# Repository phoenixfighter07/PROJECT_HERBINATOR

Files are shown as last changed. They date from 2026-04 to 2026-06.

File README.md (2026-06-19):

<!--
  GitHub project README for Project Herbinator.
  Drop this in the repo root as README.md.
-->

<div align="center">

# Project Herbinator 🌱

### Landon Wardle, Robert Cromer, Jasmine Sellers, Juan Ramirez, Zach Worcester, Hunter Mass
### May, 2026

A low-cost smart watering device that keeps small plants alive on its own.
An ESP32-S3 runs a finite-state machine that samples soil moisture, factors in
temperature and humidity, and pumps water only when the plant actually needs it.
A companion Python app monitors the device over Wi-Fi.

<!-- Badge row — these render as little pills on GitHub -->








</div>

---

## Table of Contents

1. [Overview](#overview)
2. [How It Works](#how-it-works)
3. [Hardware](#hardware)
4. [Pinout](#pinout)
5. [Firmware](#firmware)
6. [Calibration](#calibration)
7. [HTTP API](#http-api)
8. [Python Application](#python-application)
9. [Configuration](#configuration)
10. [State and LED Reference](#state-and-led-reference)
11. [Data Logging](#data-logging)
12. [Known Limitations](#known-limitations)

---

# Overview

Herbinator is an automated irrigation device for small-scale plants such as indoor gardens or
windowsill collections. It continuously monitors soil moisture and waters the plant only when the
soil dries below a calibrated threshold, then stops once the soil is satisfied. The goal is to cut
out manual watering while using water efficiently.

The brain is an **ESP32-S3** running firmware structured as a finite-state machine (FSM). The
board reads a capacitive moisture sensor and a DHT11 temperature/humidity sensor, drives a small
submersible pump, and protects itself with a float switch that prevents the pump from running dry.
All readings and pump events are logged to an SD card, and the device hosts a small HTTP server so
a Python app can monitor it remotely.

> [!NOTE]
> To see the Herbinator Roadmap and Project Specification Template
> see the Documentation folder in the repository.

# How It Works

At a high level, Herbinator spends most of its life idling and sampling the moisture sensor
occasionally. When the soil gets too dry it starts the pump, and once the soil is wet enough (or a
safety limit trips) it stops and goes back to idling.

| Step | What happens |
|:-----|:---|
| Idle / monitor | The FSM sits in `WaterLoop`, sampling the moisture sensor at a slow interval to save power. |
| Decide | If moisture drops to or below the *on* threshold, it enters `PumpOn`. The threshold is nudged by the current temperature and humidity (see VPD below). |
| Water | The pump runs until soil moisture rises past the *off* threshold, the reservoir runs dry, or a maximum run-time is reached. |
| Recover | After watering it returns to monitoring. If the pump ran for the full safety limit, it first cools down in `PumpCD`. |
| Protect | If the float switch reports no water, or a sensor stops responding, the FSM jumps to the matching error state and parks the pump. |

> [!NOTE]
> The decision threshold is adjusted using **Vapor Pressure Deficit (VPD)**, which is a measure of how fast
> a plant loses water to the air. Hotter, drier air raises the threshold so the plant is watered a
> little sooner; cool, humid air lowers it so watering is delayed. The base *on* threshold is 25%
> and the *off* threshold is 75%, with VPD shifting the *on* threshold by up to +-10%.

# Hardware

Core components for the v1.0 custom PCB:

| Component | Part | Purpose |
|:---|:-----|:---|
| Microcontroller | ESP32-S3-WROOM-1 | Runs the FSM firmware, all I/O, and Wi-Fi for Python App |
| Moisture Sensor | Capacitive soil moisture sensor | Estimates soil moisture |
| Temp/Humidity Sensor | DHT11 (U5) | Measures temperature (°C) and humidity |
| Water Pump | 5 V DC mini submersible pump | Delivers water to the plant |
| Float Switch | Magnetic float switch (J5) | Measures if water is available to pump |
| SD Card Reader | SPI SD card module (J4) | Logs readings and pump events to a `.csv` file |
| State LEDs | Green (D2), Blue (D3), Red (D4) | Visual feedback |
| Calibration Button | SW3 tactile push-button | Triggers the moisture calibration routine |
| 3.3 V regulator | AP2112K-3.3V | Powers the ESP32-S3 and sensor logic |
| 5 V regulator + jack | AMS1117-5.0 + 5.5 mm barrel jack | Powers the pump from a wall adapter |
| USB-C | USB-C receptacle (J1, FUSB302) | Alternate power input and serial programming |

> [!NOTE]
> There is no circuitry to switch from the USB-C Port to the
> barrel jack because the PCB was created to have two
> distinct power rails. Both must be plugged in for
> correct results.

> [!NOTE]
> The PCB is still being assembled. More documentation
> and photos will be available once it is done.

# Pinout

GPIO assignments as defined at the top of `ESPMain.ino`:

| Function | Pin | Function | Pin |
|:---|:---:|:---|:---:|
| Pump (servo/ESC signal) | 7 | Green LED | 13 |
| Float switch drive (high) | 0 | Blue LED | 12 |
| Float switch read | 10 | Red LED | 11 |
| Moisture sensor (analog) | 4 | Calibration button | 6 |
| DHT11 data | 5 | SD `SCK` | 3 |
| SD `CS` | 18 | SD `MISO` | 46 |
| SD `MOSI` | 8 | | |

> [!NOTE]
> The pump is driven through the `ESP32Servo` library as an ESC-style PWM signal, **not** a raw
> on/off pin. A write of `0` runs the pump at full speed and `90` stops it completely.

# Firmware

The firmware lives in `main/ESPMain/ESPMain.ino` and is built and flashed with the **Arduino IDE** targeting an **ESP32-S3**.

### Required libraries

Install these through the Arduino Library Manager:

`DHT11` · `ESP32Servo` (provides `ESP32PWM`) · `ArduinoJson`

Remaining libraries are available on the **ESP32-S3** by default.

### Build & flash

1. Install the **ESP32 board package** in the Arduino IDE.
2. Open `main/ESPMain/ESPMain.ino`.
3. Select an **ESP32-S3** board and the correct serial port.
4. Set your Wi-Fi credentials (see [Configuration](#configuration)).
5. Upload, then open the Serial Monitor at **9600 baud** (or change the baud rate specified in the code) to watch state transitions.

> [!WARNING]
> On boot the firmware **blocks until the SD card initializes**. If no card is inserted, the red
> LED stays on and the device prints an SD warning in a loop instead of starting the FSM.

# Calibration

Capacitive moisture sensors read different raw values per unit and per soil type, so Herbinator
calibrates against your specific sensor and soil. Calibration values are saved to a simulated
**EEPROM** on the **ESP32-S3** so they are non-volatile.

To calibrate, **hold the button (SW3) for 2 seconds** from the idle state. Herbinator then uses
the LEDs to guide you:

| Step | LED cue | What to do |
|:-----|:---|:---|
| Start | Red flashes 3s | Calibration mode has begun |
| Dry point | Green flashes | Place the sensor in dry soil / air, then press and hold the button |
| Wet point | Blue flashes | For best results water your plant, then place the sensor in the expected wet soil, then press and hold the button. Partially submerging the sensor in a cup of water is also acceptable. |
| Done | All LEDs blink | Done! Wait for Herbinator to resume the water loop. |

> [!NOTE]
> If the stored calibration is missing or invalid on startup, the device automatically drops into
> the calibration routine rather than watering with bad thresholds.

# HTTP API

After connecting to Wi-Fi the device registers an mDNS name and serves a small HTTP API on **port
80**. With mDNS working it is reachable at `http://herbnet.local/`, or directly by its IP address.

| Method | Endpoint | Returns |
|:---:|:---|:---|
| `GET` | `/` | JSON snapshot: `temperature`, `humidity`, `moisture`, `state`, `time` |
| `GET` | `/time` | Current time string (synced over NTP) |
| `GET` | `/temperature` | Last temperature reading |
| `GET` | `/humidity` | Last humidity reading |
| `GET` | `/moisture` | Last moisture percentage |
| `GET` | `/state` | Current FSM state name |
| `POST` | `/water` | Acknowledges a manual-water request |

<details>
<summary><b>Example <code>/</code> response</b></summary>

<br>

```json
{
  "temperature": 67,
  "humidity": 21,
  "moisture": 69,
  "state": "PumpOn",
  "time": "2026-05-28 13:45:27"
}
```

</details>

> [!NOTE]
> The `/water` endpoint currently returns a `watering` status but does not yet trigger the pump —
> the actual watering hook is still a TODO. The `/pause` and `/resume` endpoints are scaffolded in
> the firmware but commented out, so the app's pause/resume buttons have nothing to talk to yet.

# Python Application

The desktop app in `python/herbinator.py` is a **Tkinter** GUI that polls the device and displays
live data. It records each sensor's value plus the device's current state, and pulls the timestamp
from the device (synced over NTP).

### Running it

```bash
pip install requests
python herbinator.py
```

### What it shows

The window displays **Temperature**, **Humidity**, **Moisture**, **State**, and **Last Update**,
plus a scrolling log of every request and response. It refreshes automatically every **30 seconds**.

### Buttons

| Button | Action |
|:---|:---|
| Water Plant | Sends `POST /water` |
| Pause | Sends `POST /pause` |
| Pause 1 Minute | Sends `POST /pause` with a 60-second duration |
| Resume | Sends `POST /resume` |

> [!NOTE]
> Set `BASE_URL` at the top of `herbinator.py` to your device's address — either `http://herbnet.local`
> (if mDNS resolves on your network) or the device's IP shown in the Serial Monitor on boot. If the
> device is unreachable, every field shows `Disconnected` and the error appears in the log box.

# Configuration

Most tunable values are constants near the top of `ESPMain.ino`:

| Setting | Constant | Default |
|:---|:---|:---|
| Wi-Fi SSID | `ROUTER_NAME` | `HerbyIOT` |
| Wi-Fi password | `ROUTER_PASSWORD` | `herbinator` |
| mDNS name | `mdnsName` | `herbnet` → `herbnet.local` |
| Timezone offset | `gmtOffset_sec` | `-28800` (PST) |
| Moisture *on* threshold | `ON_THRESHOLD_BASE` | `0.25` |
| Moisture *off* threshold | `OFF_THRESHOLD_BASE` | `0.75` |
| Max pump run-time | `MAX_PUMP_ON_MS` | 45s |
| Long-run pump cooldown | `PUMP_CD_MILLIS` | 5 min |
| Idle sample interval | `WATER_LOOP_SAMPLE_MS` | 5s |
| Calibration hold time | `CALIBRATION_HOLD_MS` | 2s |

> [!WARNING]
> Wi-Fi credentials are stored in plain text in the source. Don't commit real network credentials
> to a public repository.

# State and LED Reference

The FSM has the following states. The three status LEDs signal what the device is doing at a glance:

| State | Meaning | LEDs |
|:---|:---|:-----|
| `MainLoop` | Validates calibration, checks for water, then enters monitoring | Green |
| `WaterLoop` | Idle monitoring; sampling soil moisture | Green |
| `PumpOn` | Pump running | Blue |
| `PumpOff` | Pump shutting off | Off |
| `PumpCD` | Cooldown after a long pump run | Red (flashing) |
| `NoWater` | Reservoir empty (float switch) — pump parked | Red + Blue |
| `RedFlash` | Entry into calibration | Red (flashing) |
| `PromptDry` | Waiting for dry calibration point | Green (flashing) |
| `PromptWet` | Waiting for wet calibration point | Blue (flashing) |
| `ButtonPressed` / `CalibrationButtonYield` | Hold-detection during calibration | — |
| `CalibrationDone` | Calibration saved | All (blinking) |
| `MoistureSensorFail` | Moisture sensor out of range / unresponsive | Red (fast flash) + Blue |
| `TempSensorFail` | DHT11 unresponsive | Red (fast flash) + Green |

# Data Logging

When an SD card is present, the firmware appends every sensor cycle and pump event to
`/herbinator_logs.txt` as CSV, flushing to the card every 30 seconds. Columns:

```text
timestamp_ms, state, rawMoist, moist_pct, on_thresh, temp_c,
humidity_pct, vpd_kpa, dht_ok, pump_on, water_raw, water_present
```

This makes it easy to pull the card afterward and analyze how the soil dried and recovered around
each watering event. It is recommended to do this in MATLAB or similar software that can crunch 
large .csv files quickly.

# Known Limitations

- **Manual watering isn't wired up.** `/water` returns a status but doesn't actually run the pump yet.
- **Pause/resume are stubs.** Those firmware endpoints are commented out, so the app's Pause / Resume / Pause 1 Minute buttons have no effect on the device.
- **CLI is a placeholder.** `python/interface.py` is an early scaffold and not yet a working interface.
- **Credentials are hardcoded.** Wi-Fi SSID/password live in the firmware source.

<!--
  Suggested next steps for the team:
  - Implement the watering hook behind /water and reinstate /pause + /resume to match the app.
  - Move Wi-Fi credentials out of source (e.g. a config the user enters, or a secrets header that's gitignored).
  - Finish interface.py or remove it if the Tkinter app is the path forward.
  - Consider documenting the BOM footprint lessons from the spec doc here too.
-->

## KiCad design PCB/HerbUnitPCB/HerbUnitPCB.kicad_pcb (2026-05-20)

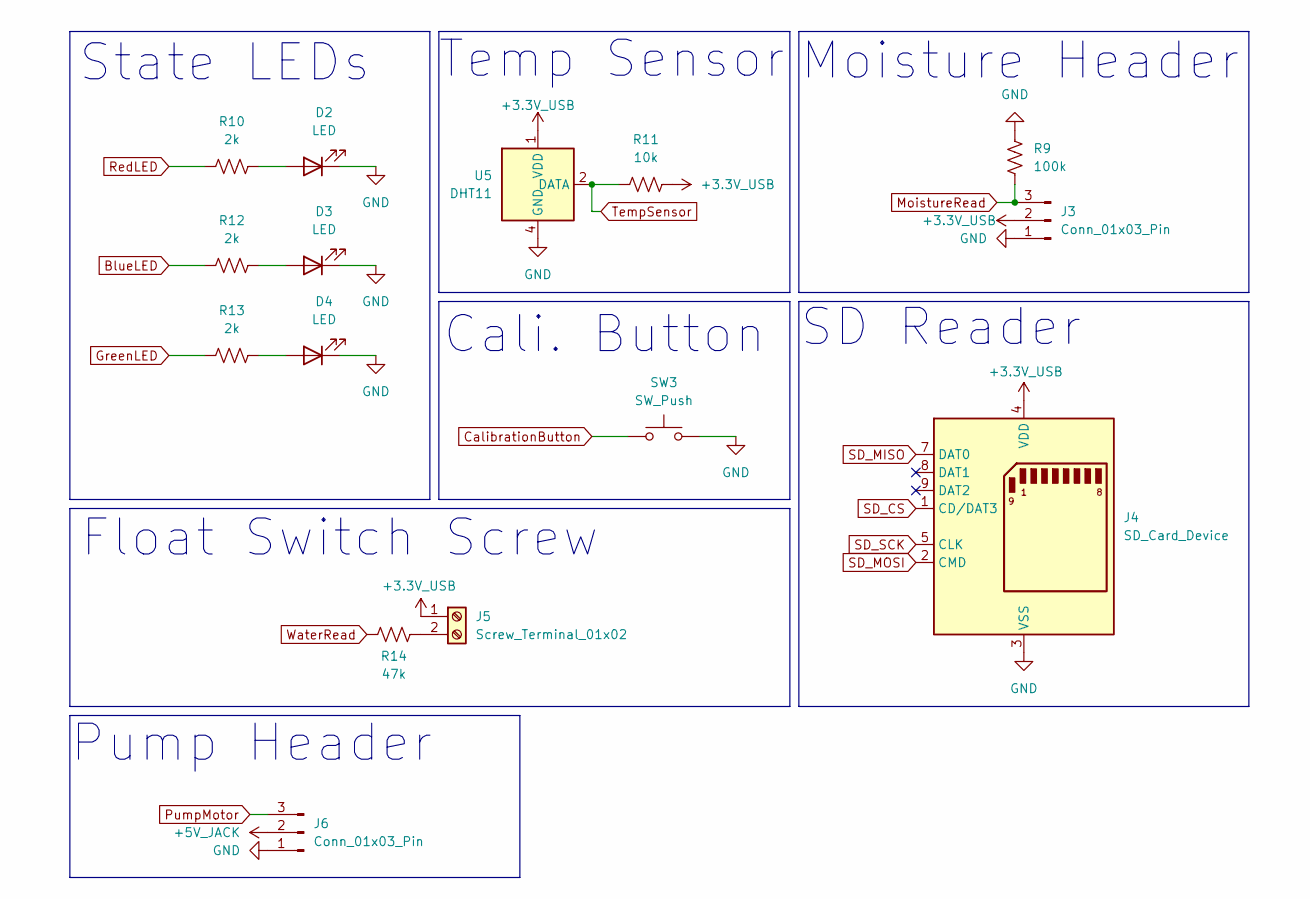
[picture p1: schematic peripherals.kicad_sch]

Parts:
D2, D3, D4: LED; LED_0201_0603Metric
J3, J6: Conn_01x03_Pin
J4: SD_Card_Device; SD_Hirose_DM1AA_SF_PEJ82
J5: Screw_Terminal_01x02
R9: 100k; R_0402_1005Metric
R10, R12, R13: 2k; R_0402_1005Metric
R11: 10k; R_0402_1005Metric
R14: 47k; R_0402_1005Metric
SW3: SW_Push; SW_Push_1P1T_NO_CK_PTS125Sx43PSMTR
U5: DHT11; Aosong_DHT11_5.5x12.0_P2.54mm

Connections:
+3.3V_USB: J3.2, J4.4 (VDD), J5.1, R11.2, U5.1 (VDD); also elsewhere on the board
BlueLED: R12.1; also elsewhere on the board
CalibrationButton: SW3.1; also elsewhere on the board
GND: D2.1 (K), D3.1 (K), D4.1 (K), J3.1, J4.3 (VSS), J4.6 (VSS), J6.1, R9.2, SW3.2, U5.4 (GND); also elsewhere on the board
GreenLED: R13.1; also elsewhere on the board
MoistureRead: J3.3, R9.1; also elsewhere on the board
unnamed: D2.2 (A), R10.2
unnamed: D3.2 (A), R12.2
unnamed: D4.2 (A), R13.2
unnamed: J5.2, R14.2
RedLED: R10.1; also elsewhere on the board
SD_CS: J4.1 (CD/DAT3); also elsewhere on the board
SD_MISO: J4.7 (DAT0); also elsewhere on the board
SD_MOSI: J4.2 (CMD); also elsewhere on the board
SD_SCK: J4.5 (CLK); also elsewhere on the board
TempSensor: R11.1, U5.2 (DATA); also elsewhere on the board
WaterRead: R14.1; also elsewhere on the board

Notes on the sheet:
Float Switch Screw
Cali. Button
State LEDs
Moisture Header
Pump Header
Temp Sensor
SD Reader

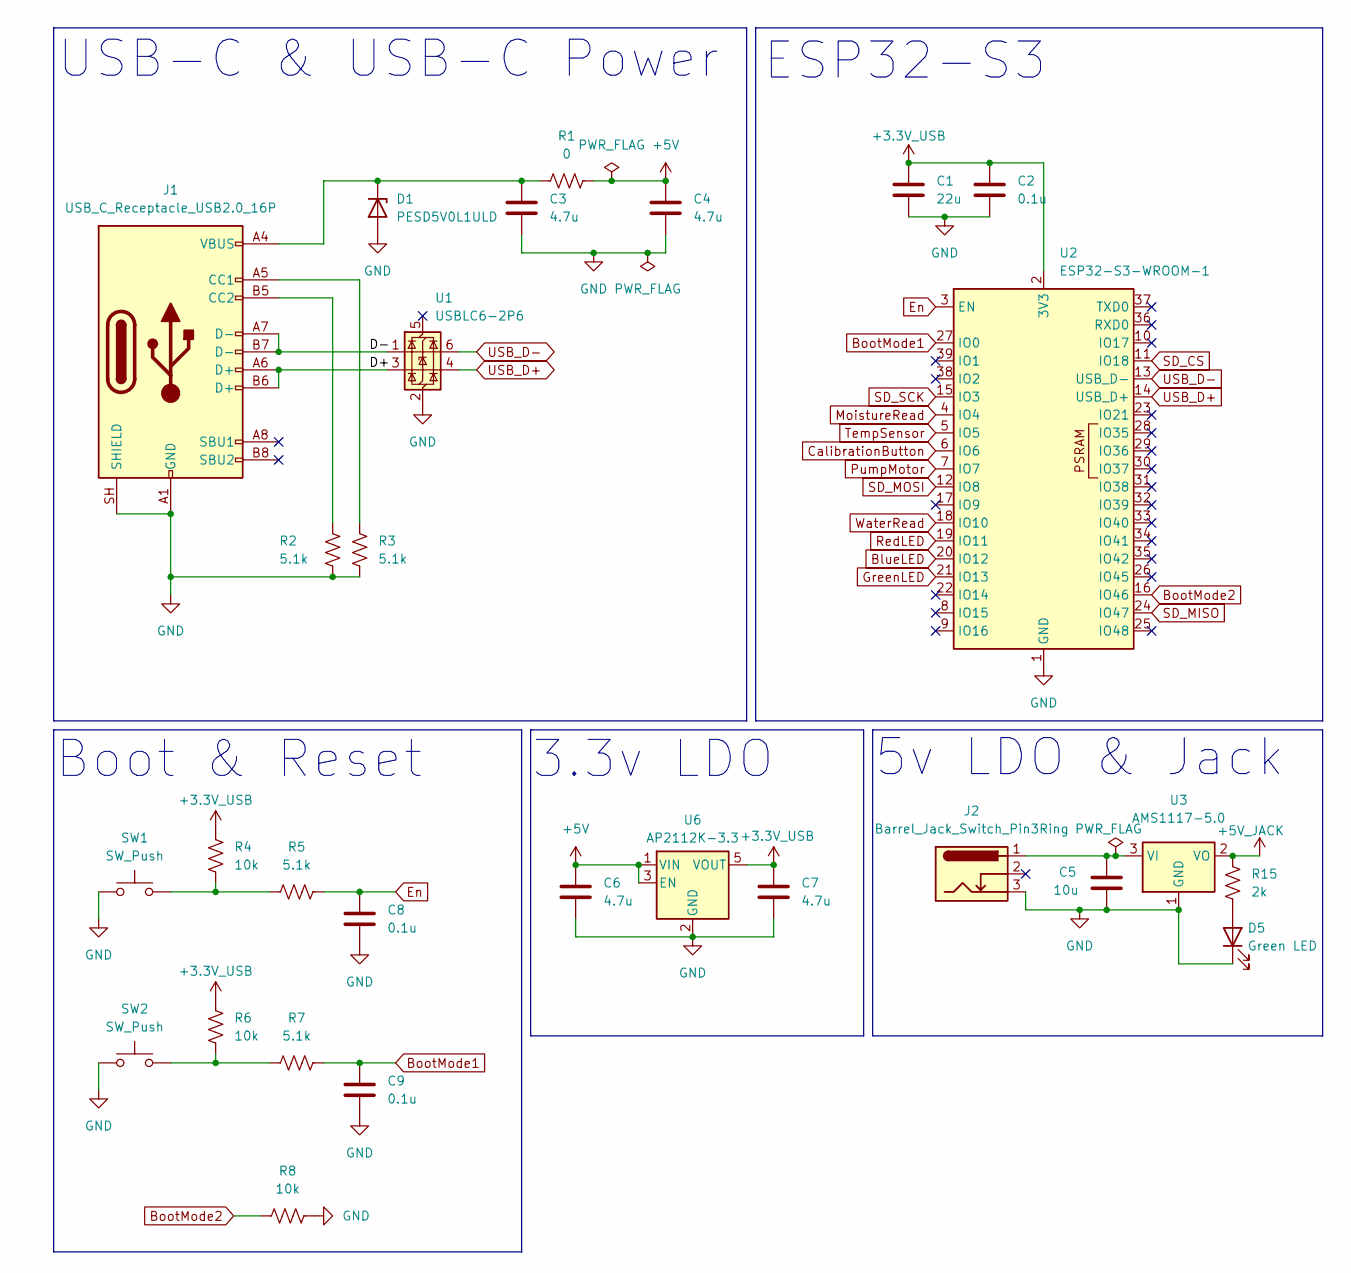
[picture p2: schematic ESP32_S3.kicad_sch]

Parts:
C1: 22u; C_0402_1005Metric
C2, C8, C9: 0.1u; C_0402_1005Metric
C3, C4, C6, C7: 4.7u; C_0402_1005Metric
C5: 10u; C_0402_1005Metric
D1: PESD5V0L1ULD; D_SOD-882D
D5: Green LED; LED_0201_0603Metric
J1: USB_C_Receptacle_USB2.0_16P; USB_C_Receptacle_G-Switch_GT-USB-7010ASV
J2: Barrel_Jack_Switch_Pin3Ring; BarrelJack_Horizontal
R1: 0
R2, R3, R5, R7: 5.1k; R_0402_1005Metric
R4, R6, R8: 10k; R_0402_1005Metric
R15: 2k; R_0402_1005Metric
SW1, SW2: SW_Push; SW_SPST_B3U-1000P
U1: USBLC6-2P6; SOT-666
U2: ESP32-S3-WROOM-1
U3: AMS1117-5.0; SOT-223-3_TabPin2
U6: AP2112K-3.3; SOT-23-5

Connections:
+3.3V_USB: C1.1, C2.1, C7.1, R4.1, R6.1, U2.2 (3V3), U6.5 (VOUT); also elsewhere on the board
+5V: C4.1, C6.1, R1.2, U6.1 (VIN), U6.3 (EN)
+5V_JACK: R15.1, U3.2 (VO)
/ESP32-S3/D+: J1.A6 (D+), J1.B6 (D+), U1.3 (I/O2)
/ESP32-S3/D-: J1.A7 (D-), J1.B7 (D-), U1.1 (I/O1)
BlueLED: U2.20 (IO12); also elsewhere on the board
BootMode1: C9.1, R7.2, U2.27 (IO0)
BootMode2: R8.1, U2.16 (IO46)
CalibrationButton: U2.6 (IO6); also elsewhere on the board
En: C8.1, R5.2, U2.3 (EN)
GND: C1.2, C2.2, C3.2, C4.2, C5.2, C6.2, C7.2, C8.2, C9.2, D1.2 (A), D5.1 (K), J1.A1 (GND), J1.A12 (GND), J1.B1 (GND), J1.B12 (GND), J1.SH (SHIELD), J2.3, R2.1, R3.2, R8.2, SW1.1, SW2.1, U1.2 (GND), U2.1 (GND), U2.40 (GND), U2.41 (GND), U3.1 (GND), U6.2 (GND); also elsewhere on the board
GreenLED: U2.21 (IO13); also elsewhere on the board
MoistureRead: U2.4 (IO4); also elsewhere on the board
unnamed: C3.1, D1.1 (K), J1.A4 (VBUS), J1.A9 (VBUS), J1.B4 (VBUS), J1.B9 (VBUS), R1.1
unnamed: D5.2 (A), R15.2
unnamed: J1.A5 (CC1), R3.1
unnamed: J1.B5 (CC2), R2.2
unnamed: R4.2, R5.1, SW1.2
unnamed: R6.2, R7.1, SW2.2
unnamed: C5.1, J2.1, U3.3 (VI)
PumpMotor: U2.7 (IO7)
RedLED: U2.19 (IO11); also elsewhere on the board
SD_CS: U2.11 (IO18); also elsewhere on the board
SD_MISO: U2.24 (IO47); also elsewhere on the board
SD_MOSI: U2.12 (IO8); also elsewhere on the board
SD_SCK: U2.15 (IO3); also elsewhere on the board
TempSensor: U2.5 (IO5); also elsewhere on the board
USB_D+: U1.4 (I/O2), U2.14 (USB_D+)
USB_D-: U1.6 (I/O1), U2.13 (USB_D-)
WaterRead: U2.18 (IO10); also elsewhere on the board

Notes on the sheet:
ESP32-S3
5v LDO & Jack
3.3v LDO
Boot & Reset
USB-C & USB-C Power

Board: 2 copper layers, 39 parts (0 on the bottom side), 32 nets, no tracks yet.

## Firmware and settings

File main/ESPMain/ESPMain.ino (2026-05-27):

/**
 * @file ESPMain.ino
 * Brain for ESP Herbinator units. Uses a FSM to read sensor data
 * and decide when to water the plant.
 *
 * @author Landon Wardle, Hunter Maas
 * @date 5/26/2026
 * @version 1.0
 */

 /* Standard Library Imports */
#include <DHT11.h>
#include <ESP32Servo.h>
#include <ESP32PWM.h>
#include <EEPROM.h>
#include <SPI.h>
#include <SD.h>
#include <WiFi.h> // wifi module for esp32
#include <string.h> // string management
#include <WebServer.h> // web server utility for esp32
#include <ESPmDNS.h> // map ip address to a name
#include <time.h> // up to date time over NTP
#include <ArduinoJson.h> // json formatting

#define MAX_CONNECT_ATTEMPTS 20
/**
 * Store last value for:
 * Temperature
 * Moisture
 * Humidity
 * State 
 * Time (Full timestamp)
 * Unit name
*/

/* Exposed variables for JSON */

/* Last valid DHT11 readings. */
float lastTempC = 22.0f;
float lastHumidity = 50.0f;

/* Last valid moisture */
float lastMoisturePct = 0.0f;

/* State */
const char* currentStateName = "";

/* State Enums */
enum class State {
  MainLoop,
  RedFlash,
  WaterLoop,
  PumpOn,
  PumpOff,
  PumpCD,
  NoWater,
  PromptDry,
  PromptWet,
  CalibrationDone,
  ButtonPressed,
  CalibrationButtonYield,
  MoistureSensorFail,
  TempSensorFail
};

/* State Names in an Array for simplicity */
const char* const stateNames[] = { 
  "MainLoop", 
  "RedFlash", 
  "WaterLoop", 
  "PumpOn", 
  "PumpOff", 
  "PumpCD", 
  "NoWater", 
  "PromptDry",
  "PromptWet",
  "CalibrationDone", 
  "ButtonPressed",
  "CalibrationButtonYield",
  "MoistureSensorFail",
  "TempSensorFail"
};

/* LED Colors */
enum class LEDColor {
  Green,
  Blue,
  Red
};

/* ESP32 Settings -----------------------------------------------------------------*/
/* Networking*/
String ROUTER_NAME = "HerbyIOT";
String ROUTER_PASSWORD = "herbinator";
//String ROUTER_NAME;
//String ROUTER_PASSWORD;
String mdnsName = "herbnet";

// NTP server
const char* ntpServer = "pool.ntp.org"; // atomic clock ntp pooler
const long  gmtOffset_sec = -28800;   // pst is 28800 secs behind gmt
const int   daylightOffset_sec = 3600; // 3600 secs added for daylight savings

// Web server port open 80 http
WebServer server(80);

/* Pins */
const int PUMP_MOTOR = 7;
const int WATER_HIGH = 0;
const int WATER_READ = 10;
const int MOISTURE_READ = 4;
const int DHT_SENSOR_PIN = 5;
const int GREEN_LED = 13;
const int BLUE_LED = 12;
const int RED_LED = 11;
const int BUTTON = 6;
const int SD_CS = 18;
const int SD_MOSI = 8;
const int SD_SCK = 3; // Clk
const int SD_MISO = 46;

/* The baud rate to the serial monitor. */
const unsigned int BAUD_RATE = 9600;

/**
 * The max value the Microcontroller can read of an analog signal
 * Used for verifying if the recorded moisture calibration is legit
*/
const unsigned int ANALOG_MAX = 4096;

/**
 * How frequently the sensors will sample.
 * Essentially our clock cycle time, which recall is the inverse of frequency.
*/
const unsigned long SENSOR_SAMPLE_MS = 1000UL;

/* Constant for when water reading fails. */
const int NO_WATER_READING = -1;

/* How long Herbinator waits until starting main FSM after initialization. */
const unsigned int INIT_DELAY_MS = 1000;

/* How long to hold the calibration button to switch to calibration mode. */
const unsigned int CALIBRATION_HOLD_MS = 2000;

/* SD Settings ---------------------------------------------------------------------- */



/* The reference to the filename to write logs to. */
const char* LOG_FILENAME = "/herbinator_logs.txt";

/* The header of the .csv file the logs write to. */
const char* CSV_HEADER = "timestamp_ms,state,rawMoist,moist_pct,on_thresh,temp_c,humidity_pct,vpd_kpa,dht_ok,pump_on,water_raw,water_present";

/* How long between each attempt at flushing the sensor data to the log file. */
const unsigned long FLUSH_CYCLE_TIME = 30UL * 1000UL;

/* The frequency the SD class operates at */
const unsigned long SD_FREQUENCY = 4000000UL;

/* Watering Settings -----------------------------------------------------------------*/



/**
 * How frequently the sensors will sample when in the
 * WaterLoop (Idle) state. This should be slower than
 * SENSOR_SAMPLE_MS because Herbinator is in idle the
 * majority of its operating time.
*/
const unsigned int WATER_LOOP_SAMPLE_MS = 5000UL;

/* Water threshold Herbinator must be below to trigger the pump. */
const float ON_THRESHOLD_BASE  = 0.25; 

/* Water threshold Herbinator cannot be above for the pump to be powered. */
const float OFF_THRESHOLD_BASE = 0.75;

/* Threshold for when we detect current going thru the water to verify that the water is in the container. */
const int WATER_THRESHOLD = 4000;

/* The percent +/- added to the threshold clamp to ensure proper operation of the moisture sensor. */
const float MOIST_FAIL_GRACE = 0.20f;

/* Minimum moisture expected of the moisture sensor to validate proper operation. */
const unsigned int MIN_RAW_MOIST = 110;

/* VPD Settings -----------------------------------------------------------------*/



/**
 *                 Vapor Pressure Deficit (VPD) Adjustment
 * 
 * VPD (kPa) measures evaporative demand. Higher VPD = plant transpires faster.
 * VPD = SVP(T) - (RH/100)*SVP(T), where SVP uses the Magnus formula.
 * Low VPD  (< VPD_LOW_KPA)  -> low demand -> delay watering (lower ON threshold)
 * High VPD (> VPD_HIGH_KPA) -> high demand -> water sooner  (raise ON threshold)
*/

/* Minimal evaporative stress in kPa. */
const float VPD_LOW_KPA = 0.4f;

/* High evaporative stress in kPa. */
const float VPD_HIGH_KPA = 1.2f;

/* The maximum VPD can influence ON_THRESHOLD_BASE. */
const float VPD_ADJUST_MAX = 0.1f;

/* Pump Settings -----------------------------------------------------------------*/



/* Value from 0 to 80 describing the speed of the pump. 0 fastest 80 slowest. */
const uint8_t PUMP_ON_DEGREE = 0;

/** 
 * The speed of the pump when turning it off. 
 * 90 stops operation completely.
*/
const uint8_t PUMP_OFF_DEGREE = 90;

/* The longest the pump can run for. */
const unsigned long MAX_PUMP_ON_MS = 45UL * 1000UL;

/* The default cooldown of the pump when turning the pump off. */
const unsigned long MIN_PUMP_CD = 1000UL;

/** 
 * The cooldown of the pump when it auto-
 * terminates after MAX_PUMP_ON_MS seconds.
*/
const unsigned long PUMP_CD_MILLIS = static_cast<unsigned long>(5 * 60UL * 1000UL);

/* Memory Settings ----------------------------------------------------------------- */



/** 
 * The address in EEPROM memory of where to store the 
 * wet value for the moisture sensor calibration. 
 * NOTE: The value being stored is an integer, so it 
 *       will take 3 addresses AFTER the address set
 *       here!
*/
const unsigned int SENSOR_WET_ADDRESS = 0;

/** 
 * The address in EEPROM memory of where to store the 
 * wet value for the moisture sensor calibration. 
 * NOTE: The value being stored is an integer, so it 
 *       will take 3 addresses AFTER the address set
 *       here!
*/
const unsigned int SENSOR_DRY_ADDRESS = 4;

/* The size of EEPROM memory to simulate. */
const unsigned int EEPROM_SIZE = 8;
/**
 * The number of consecutive moisture sensor fails 
 * that must occur before an error state is entered.
 */
const unsigned int TEMP_READ_FAIL_THRESHOLD = 10;

/* LED Settings -----------------------------------------------------------------*/



/* How long the RED LEDs flash for. */
const unsigned int RED_FLASH_DURATION_MS = 3000;

/* How long between flashes when using an LED to indicate a state. */
const unsigned int PROMPT_FLASH_INTERVAL_MS = 1000;
const unsigned int PROMPT_FLASH_INTERVAL_MS_FAST = 200;

/* How long between flashing the Red LED on the calibrate state. */
const unsigned int RED_FLASH_MS = 500;

/* How long to wait between each flash to show calibration is done. */
const unsigned int CALIBRATION_DONE_DELAY_MS = 500;

/* State  ----------------------------------------------------------------- */



/* General state variables. */
bool pumpOn = false;
bool lastBtnDown = false;
bool tempSensorFail = false;
bool moistureSensorFail = false;
bool validCalibration = false;

unsigned long lastLEDFlash = 0;
unsigned long pumpStartMs = 0;
unsigned long lastWaterMs = 0;
unsigned long lastSampleMs = 0;
unsigned long pumpOffCDTime = 0;
unsigned long btnDown = 0;
unsigned long now = 0;
unsigned long stateEnteredMs = 0;

unsigned int readFailCount = 0;
unsigned long flashBegin = 0;

/* Current calibration values for the moisture sensor. */
int moistureDry = 0;
int moistureWet = 0;

/* DHT Sensor object using DHT library */
DHT11 dhtSensor(DHT_SENSOR_PIN);

/* Pump object using servo library */
Servo pump;

/* Current state of Herbinator */
State currentState;

/* Where ButtonPressed should return on early release */
State preButtonState = State::PromptDry;

/**
 * SPI bus instance so we can pick the pins explicitly
 * On the ESP32-S3 this maps to the FSPI/HSPI peripheral.
 */
SPIClass sdSPI(FSPI);

/* Log File class. */
File logFile;

/* VPD Helpers ----------------------------------------------------------------- */



/* See documentation in VPD Settings for how VPD works. */

/**
 * Magnus formula: saturation vapor pressure in kPa
 * @param tempC the temperature in Celcius.
 * @return the pressure of the vapor with the given temperature tempC
 */
float saturationVaporPressure(const float tempC) {
  return 0.6108f * exp(17.27f * tempC / (tempC + 237.3f));
}

/**
 * Computes VPD.
 * @param tempC the temperature in Celcius.
 * @param humidity the humidity as a percent.
 * 
 * @note humidity should be given as a percent, not a value from 0 to 1!
 * 
 * @return VPD as a float value in kPa.
 */
float computeVPD(const float tempC, const float humidity) {
  float svp = saturationVaporPressure(tempC);
  return svp * (1.0f - humidity / 100.0f);
}

/**
 * Calculates the threshold for Herbinator to water the plant based off of VPD.
 * @param tempC the temperature in Celcius.
 * @param humidity the humidity as a percent.
 * 
 * @note humidity should be given as a percent, not a value from 0 to 1!
 * 
 * @return the adjusted threshold value for Herbinator to water.
 */
float getAdjustedOnThreshold(const float tempC, const float humidity) {
  float vpd = computeVPD(tempC, humidity);

  // Normalise VPD into [0,1] over the expected operating range
  float t = (constrain(vpd, VPD_LOW_KPA, VPD_HIGH_KPA) - VPD_LOW_KPA)
            / (VPD_HIGH_KPA - VPD_LOW_KPA);

  // Map to [-VPD_ADJUST_MAX, +VPD_ADJUST_MAX]
  float adjust = (t - 0.5f) * 2.0f * VPD_ADJUST_MAX;
  return constrain(ON_THRESHOLD_BASE + adjust, 0.05f, 0.95f);
}

/**
 * Calculates the threshold for Herbinator to water the plant based off of VPD.
 * @param LED the LED as an enum.
 * 
 * @return the pin on the microcontroller that leads to the pin.
 */
int getLEDPin(const LEDColor LED) {
  switch (LED) {
    case LEDColor::Green: return GREEN_LED;
    case LEDColor::Blue: return BLUE_LED;
    case LEDColor::Red: return RED_LED;
    default: return 0;
  }
}

/**
 * Sets an LED to be enabled.
 * @param LED the LED as an enum.
 * @param enabled if the LED is enabled.
 */
void setLEDEnabled(const LEDColor LED, const bool enabled) {
  digitalWrite(getLEDPin(LED), enabled ? HIGH : LOW);
}

/**
 * Disables all LEDs.
 */
void disableLEDS() {
  setLEDEnabled(LEDColor::Green, false);
  setLEDEnabled(LEDColor::Blue, false);
  setLEDEnabled(LEDColor::Red, false);
}

/**
 * Enables all LEDs.
 */
void enableLEDS() {
  setLEDEnabled(LEDColor::Green, true);
  setLEDEnabled(LEDColor::Blue, true);
  setLEDEnabled(LEDColor::Red, true);
}

/**
 * Transitions the FSM to a new state and records when it was entered.
 * Logs the transition to serial for debugging.
 *
 * @param next the state to transition to.
 */
void transitionTo(const State next) {
  currentState = next;
  stateEnteredMs = millis();
  currentStateName = stateNames[static_cast<int>(next)];

  Serial.print("Transition -> ");
  Serial.println(currentStateName);
}
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
void loop() {
  server.handleClient(); // continuous client handling
  now = millis();
  if (logFile && millis() - last_flush > FLUSH_CYCLE_TIME) {
    logFile.flush();
    last_flush = millis();
    Serial.println("Flushing buffer to SD card!");
  }

  bool btnDownNow = isButtonDown();
  if (btnDownNow && btnDownNow != lastBtnDown) {
    btnDown = now;
  }
  lastBtnDown = btnDownNow;

  // Debug
  //Serial.printf("Last moisture percent is %f.\n", lastMoisturePct);
  //Serial.printf("Current state is %s.\n", currentStateName);

  // Failure states — preempt whatever state we were in
  if (tempSensorFail && currentState != State::TempSensorFail) {
    transitionTo(State::TempSensorFail);
  } else if (moistureSensorFail && currentState != State::MoistureSensorFail) {
    transitionTo(State::MoistureSensorFail);
  }

  switch (currentState) {
    // ── MainLoop ─────────────────────────────────────────────────────
    // Hub state: validate calibration, check for button-initiated
    // calibration, detect missing water, then enter WaterLoop.
    case State::MainLoop: {
      setLEDEnabled(LEDColor::Green, true);
      setLEDEnabled(LEDColor::Blue, false);
      setLEDEnabled(LEDColor::Red, false);

      // Button held → enter calibration
      if (isButtonDown()) {
        if (now - btnDown > CALIBRATION_HOLD_MS) {
          Serial.println("User initiated calibration!");
          beginRedFlash();
        }
        break;  // stay in MainLoop while button is held but not long enough
      }

      // Bad calibration values → force recalibration
      validCalibration = moistureWet >= 0 && moistureDry <= ANALOG_MAX && moistureWet < moistureDry;

      if (!validCalibration) {
        Serial.println("Bad calibration values!");
        beginRedFlash();
        break;
      }

      // Everything OK → enter watering mode
      transitionTo(State::WaterLoop);
      break;
    }

    // ── RedFlash ─────────────────────────────────────────────────────
    // Flash red for 3 seconds, then start dry calibration prompt.
    case State::RedFlash: {
      processFlash(LEDColor::Red, RED_FLASH_MS);

      if (now - flashBegin > RED_FLASH_DURATION_MS) {
        disableLEDS();
        transitionTo(State::PromptDry);
      }
      break;
    }

    // ── PromptDry ────────────────────────────────────────────────────
    // Flash green LED — waiting for user to press & hold button with
    // sensor in dry soil / air.
    case State::PromptDry: {
      setLEDEnabled(LEDColor::Blue, false);
      setLEDEnabled(LEDColor::Red, false);
      processFlash(LEDColor::Green, PROMPT_FLASH_INTERVAL_MS);

      if (isButtonDown()) {
        preButtonState = State::PromptDry;
        transitionTo(State::ButtonPressed);
      }
      break;
    }

    // ── PromptWet ────────────────────────────────────────────────────
    // Flash blue LED — waiting for user to press & hold button with
    // sensor in wet soil / water.
    case State::PromptWet: {
      setLEDEnabled(LEDColor::Green, false);
      setLEDEnabled(LEDColor::Red, false);
      processFlash(LEDColor::Blue, PROMPT_FLASH_INTERVAL_MS);

      if (isButtonDown()) {
        preButtonState = State::PromptWet;
        transitionTo(State::ButtonPressed);
      }
      break;
    }

    // ── ButtonPressed ────────────────────────────────────────────────
    // Shared hold-detection state for calibration.  While held, stays
    // here.  On release before the hold threshold, returns to the
    // previous prompt.  On successful hold, records the calibration
    // value and advances.
    case State::ButtonPressed: {
      if (!isButtonDown()) {
        // Released too early — go back to the prompt
        transitionTo(preButtonState);
        break;
      }

      if (now - btnDown > CALIBRATION_HOLD_MS) {
        int wrote;
        readMoistureSensor(&wrote);

        if (preButtonState == State::PromptDry) {
          EEPROM.put(SENSOR_DRY_ADDRESS, wrote);
          moistureDry = wrote;
          Serial.print("Dry=");
          Serial.println(wrote);
          transitionTo(State::CalibrationButtonYield);
        } else {
          EEPROM.put(SENSOR_WET_ADDRESS, wrote);
          moistureWet = wrote;
          Serial.print("Wet=");
          Serial.println(wrote);
          transitionTo(State::CalibrationDone);
        }
        // Save changes
        EEPROM.commit();
      }
      // else: still holding, stay in ButtonPressed
      break;
    }

    // ── CalibrationButtonRelease ─────────────────────────────────
    // Waits for the button to be released.
    // Then, goes to prompt wet state.
    case State::CalibrationButtonYield: {
      enableLEDS();
      if (isButtonDown()) break;

      transitionTo(State::PromptWet);
      break;
    }

    // ── CalibrationDone ──────────────────────────────────────────────
    // Quick LED celebration, then back to MainLoop.
    case State::CalibrationDone: {
      disableLEDS();  delay(CALIBRATION_DONE_DELAY_MS);
      enableLEDS();   delay(CALIBRATION_DONE_DELAY_MS);
      disableLEDS();  delay(CALIBRATION_DONE_DELAY_MS);
      enableLEDS();   delay(CALIBRATION_DONE_DELAY_MS);
      disableLEDS();

      transitionTo(State::MainLoop);
      break;
    }

    // ── WaterLoop ────────────────────────────────────────────────────
    // Core monitoring state.  Reads sensors at SENSOR_SAMPLE_MS rate,
    // decides whether to start pumping, flags errors.
    case State::WaterLoop: {
      setLEDEnabled(LEDColor::Green, true);
      setLEDEnabled(LEDColor::Blue, false);
      setLEDEnabled(LEDColor::Red, false);

      int rawWaterPresent = analogRead(WATER_READ);
      bool waterPresent = rawWaterPresent >= WATER_THRESHOLD;

      // ── No water → Error ──
      if (!waterPresent) {
        transitionTo(State::NoWater);
        break;
      }

      if (!canReadSensors(WATER_LOOP_SAMPLE_MS)) break;

      // ── Sensor reads ──
      int rawMoist;
      float moistPct = readMoistureSensor(&rawMoist);

      bool readSuccess = readDHT();

      float onThreshold = getAdjustedOnThreshold(lastTempC, lastHumidity);

      printCSVRow("WaterLoop", rawMoist, moistPct, onThreshold,
                  readSuccess, rawWaterPresent, waterPresent);

      // ── Moisture low → start pumping ──
      if (moistPct <= onThreshold) {
        transitionTo(State::PumpOn);
        break;
      }

      if (now - lastWaterMs < MIN_PUMP_CD) break;

      transitionTo(State::MainLoop);
      break;
    }

    // ── PumpOn ───────────────────────────────────────────────────
    // Pump is running.  Re-reads sensors each cycle; stays here while
    // moisture is still low and pump hasn't run too long.
    case State::PumpOn: {
      setLEDEnabled(LEDColor::Blue, true);
      setLEDEnabled(LEDColor::Green, false);
      setLEDEnabled(LEDColor::Red, false);

      if (!pumpOn) pumpSet(true);  // turn on once on first entry

      if (isButtonDown()) {
        transitionTo(State::PumpOff);
        break;
      }

      if (!canReadSensors()) break;

      int rawMoist;
      float moistPct = readMoistureSensor(&rawMoist);

      int rawWaterPresent = analogRead(WATER_READ);
      bool waterPresent = rawWaterPresent >= WATER_THRESHOLD;

      printCSVRow("PumpOn", rawMoist, moistPct,
                  getAdjustedOnThreshold(lastTempC, lastHumidity),
                  false, rawWaterPresent, waterPresent);

      bool pumpTooLong = (now - pumpStartMs) > MAX_PUMP_ON_MS;

      // Exit conditions: moisture satisfied OR pump safety timeout
      if (moistPct >= OFF_THRESHOLD_BASE || pumpTooLong || !waterPresent) {
        transitionTo(State::PumpOff);
        break;
      }

      // Otherwise keep pumping (self-loop)
      break;
    }

    // ── PumpOff ──────────────────────────────────────────────────
    // Turns pump off.  Routes to PumpCD if pump ran too long (safety),
    // otherwise straight back to MainLoop.
    case State::PumpOff: {
      bool wasTooLong = (now - pumpStartMs) > MAX_PUMP_ON_MS;
      pumpSet(false);
      disableLEDS();

      if (isButtonDown()) {
        transitionTo(State::MainLoop);
        break;
      }

      if (wasTooLong) {
        pumpOffCDTime = now + PUMP_CD_MILLIS;
        transitionTo(State::PumpCD);
      } else {
        transitionTo(State::MainLoop);
      }
      break;
    }

    // ── PumpCD (Pump Cooldown) ───────────────────────────────────────
    // Enforces a cooldown period after the pump ran for too long.
    // Flashes red while cooling down, then returns to MainLoop.
    case State::PumpCD: {
      processFlash(LEDColor::Red, PROMPT_FLASH_INTERVAL_MS);
      setLEDEnabled(LEDColor::Green, false);
      setLEDEnabled(LEDColor::Blue, false);
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

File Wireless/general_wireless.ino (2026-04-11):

#ifdef ESP32
  #include <WiFi.h>
#elif defined(ARDUINO_UNOWIFIR4)
  #include <WiFiS3.h>
#else
  #error "please have an esp32 or arduino r4 wifi board"
#endif


#include <string.h>

/*This file contains the code for the arduino wifi. This will eventually be put in the main file for the arduino code*/
#define MAX_CONNECT_ATTEMPTS 20

// not using c strings because c++ strings are easier to deal with
String ROUTER_NAME = "HerbyIOT";
String ROUTER_PASSWORD = "herbinator";

String getString(String);
void connect(String, String);



void setup(){ // in the futire, this code may be moved to its own function so that we can do more with it on startup
  Serial.begin(9600); // so that terminal can be read
  
  /*
  while (!Serial){
    ; // waits for arduino to connect
  }

  ROUTER_NAME = getString("Enter router name.");
  ROUTER_NAME.trim();
  
  ROUTER_PASSWORD = getString("Enter router password.");\
  ROUTER_PASSWORD.trim();
  */
  connect(ROUTER_NAME, ROUTER_PASSWORD);


}

void loop(){
  // will add connection code and probably put it in a separate file.
}


// this function enables the boards to connect to a wifi router
void connect(String name, String password){

  WiFi.begin(ROUTER_NAME.c_str(), ROUTER_PASSWORD.c_str());
 
  for (int attempts = 0; attempts < MAX_CONNECT_ATTEMPTS && WiFi.status() != WL_CONNECTED; attempts++){   // delay for connetion to the 
    delay(500); // pauses
  }

  if (WiFi.status() == WL_CONNECTED){
    Serial.println("Connected");
  } else Serial.println("Failed to connect. Please try again.");
}

String getString(String prompt){
  Serial.readString(); // flushes whatever is in the input
  Serial.println(prompt);

  while(Serial.available() <= 0); // BLANK--buffer for user to enter input. Will be exited once input provided

  return Serial.readStringUntil('\n');

}

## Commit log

2026-03-28 Sensor Fail Added
2026-03-30 Added float switch.
    Added float switch support.
    Also fixed a bug with pump not having water and not turning off.
2026-04-06 Add HerbNet web app prototype for ESP32 hub management (#1)
    Captive portal (portal.html) for WiFi SoftAP provisioning and
    dashboard (index.html) for managing Herbinator nodes. Includes
    shared CSS with dark theme. All structured for future REST API
    backend integration.
2026-04-11 Wireless simplification
2026-04-17 KiCad Project
2026-04-27 8 Hour Test
    Tested Herbinator for 8 hours.
    Also fixed minor bugs in main.ino and made the C# logger failsafe.
    [LogFile.csv]
2026-05-09 Removed Arduino Serial Reader
2026-05-15 Schematic Progress
    - Finished ESP Schematic
    - Began Peripherals Schematic
    [ESP32_S3.kicad_sch, HerbUnitPCB.kicad_sch, peripherals.kicad_sch]
2026-05-19 Peripherals
    Finished most of the Peripherals.
    - Added temp sensor
    - Added Moisture sensor
    - Added float switch
    - Added SD card reader/writer
    - Still need to add barrel jack/pump
    [ESP32_S3.kicad_sch, peripherals.kicad_sch]
2026-05-20 Started PCB design
    - Assigned footprints to remaining components
    - Brought components into PCB editor and laid them out in general groups
    [ESP32_S3.kicad_sch, HerbUnitPCB.kicad_pcb, peripherals.kicad_sch]
2026-05-22 Wireless hardcoded values
2026-05-27 dennis not working with us
    [ESPMain.ino]
